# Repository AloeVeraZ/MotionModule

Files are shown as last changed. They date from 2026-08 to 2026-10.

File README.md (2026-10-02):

# MotionModule

> [!WARNING]
> **You are on `testing`, the experimental development branch.**
>
> Changes here are still being developed and tested. Running this branch may
> introduce bugs, break features that work on `main`, or change how your robot
> behaves. An update can also introduce new issues, even if an earlier testing
> version worked for you. Use [`main`](https://github.com/AloeVeraZ/MotionModule/tree/main)
> for normal robot use; choose `testing` when you want to try experimental changes
> and troubleshoot problems. Raise the wheels when checking a testing build.
>
> To return an installed controller to the main branch, run:
> ```bash
> motionmodule install main
> ```

MotionModule is an open-source Raspberry Pi robot controller for eight brushed
DC motors, a PCA9685 servo board with sixteen outputs, and a Pi-connected IMU.
The idea is to bring the controller and expansion functions of a REV Robotics
Control Hub and Expansion Hub together in one buildable, open-source project.
Anyone can build it using the supplied code, wiring guide, bill of materials
and enclosure CAD.

The reusable runtime owns GPIO, I2C, safety, networking, diagnostics, and the
browser dashboard. Each robot is one separate Python folder containing its own
behavior and an optional hardware map, so the same installation can run a Mecanum, tank,
walking, or other robot.

**Build it, wire it correctly, and run it from `main`.** The main branch is the
ready-to-use version for the documented hardware. Changes are developed and
tested on `testing` before they are merged into `main`; `testing` is the
development branch and can contain unfinished changes. The branches may match
immediately after a merge, then diverge as development continues.

Keep a physical motor-power cutoff within reach and raise the wheels when
checking a newly assembled robot. Follow the [wiring and power guide](docs/PINOUT.md).

## Wiring at a glance

The complete reference wiring below shows the Pi, all four motor drivers,
the PCA9685 servo board, the MPU6500 IMU and the power rails. Labels use
**physical Pi header pin numbers**. Wire colors match **Debug → Wiring →
Follow the signal** in the dashboard, which also includes this diagram below
**Names you can use in code**.

[Open the full-size diagram](docs/images/motionmodule-complete-wiring.png)
or use the [scalable SVG](docs/images/motionmodule-complete-wiring.svg).
See the [pinout guide](docs/PINOUT.md) for the connection tables and power details.

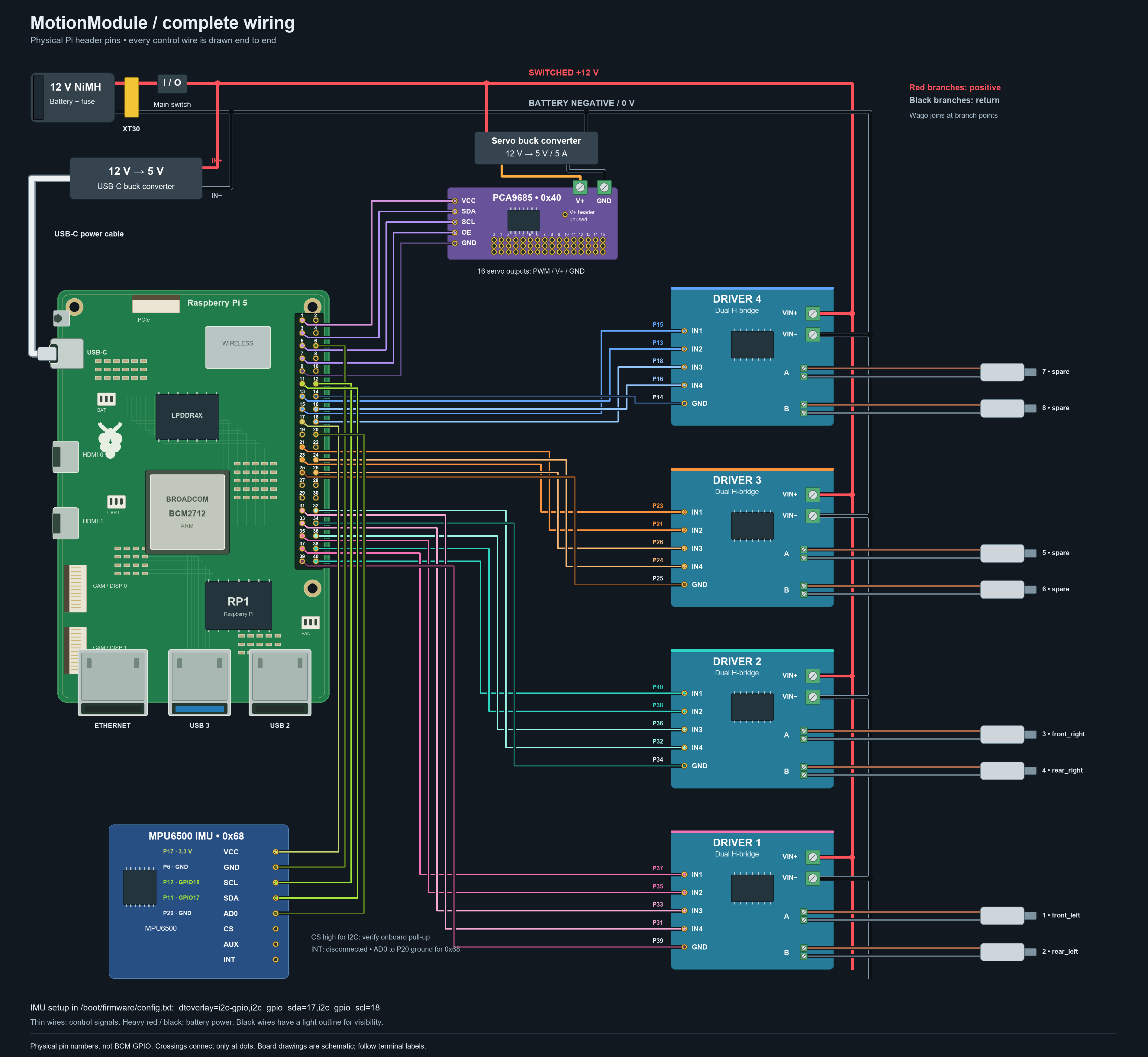
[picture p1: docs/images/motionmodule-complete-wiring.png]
Complete MotionModule wiring diagram


## Built for a personal Mecanum test robot

These photos show MotionModule in use on the owner's personal Mecanum testing
robot. The electronics are reusable; this four-wheel drivetrain is one example
of what the controller can run.

| Installed motion module | Controller with the cover removed |
| --- | --- |
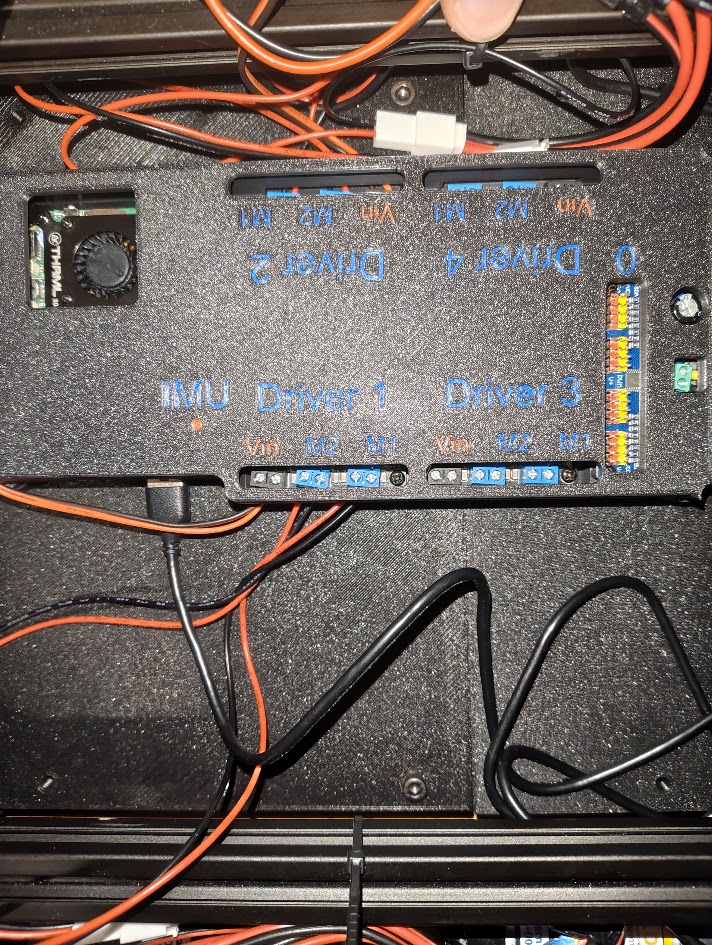
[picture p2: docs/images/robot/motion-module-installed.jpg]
MotionModule mounted in the Mecanum robot
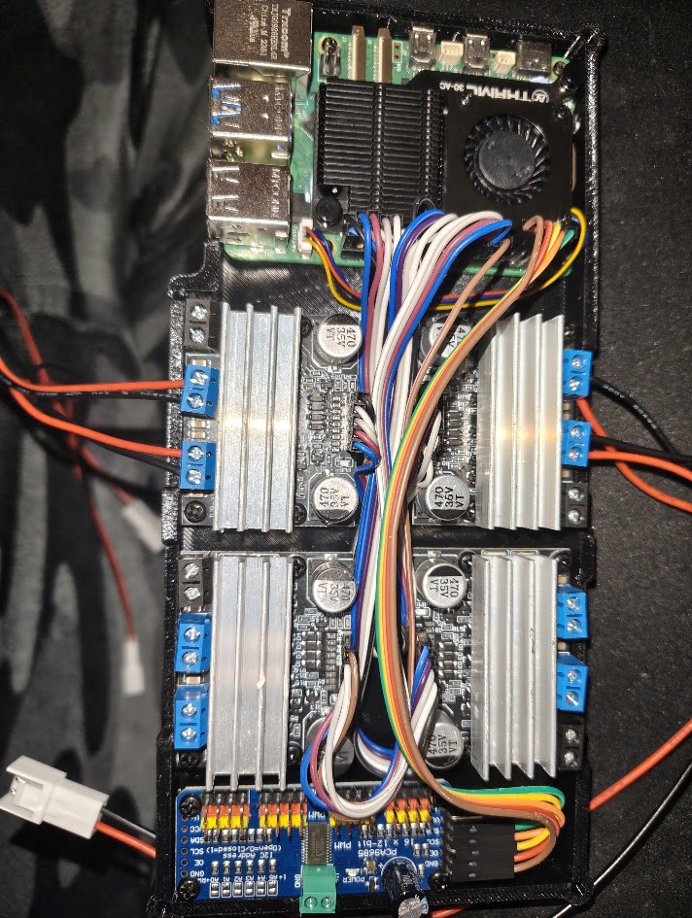
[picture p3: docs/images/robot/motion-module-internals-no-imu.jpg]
Pi, four motor drivers and PCA9685 inside the module, without the IMU plugged in
|  |  |

The open-module photo shows the build **without the IMU plugged in**. The
current build adds a Pi-connected MPU6500, supported by the included sensor
code for heading assist and autonomous turns. The labelled cover keeps the
motor-driver terminals and servo channels accessible.

<details>
<summary>Another view of the motion-module cover</summary>

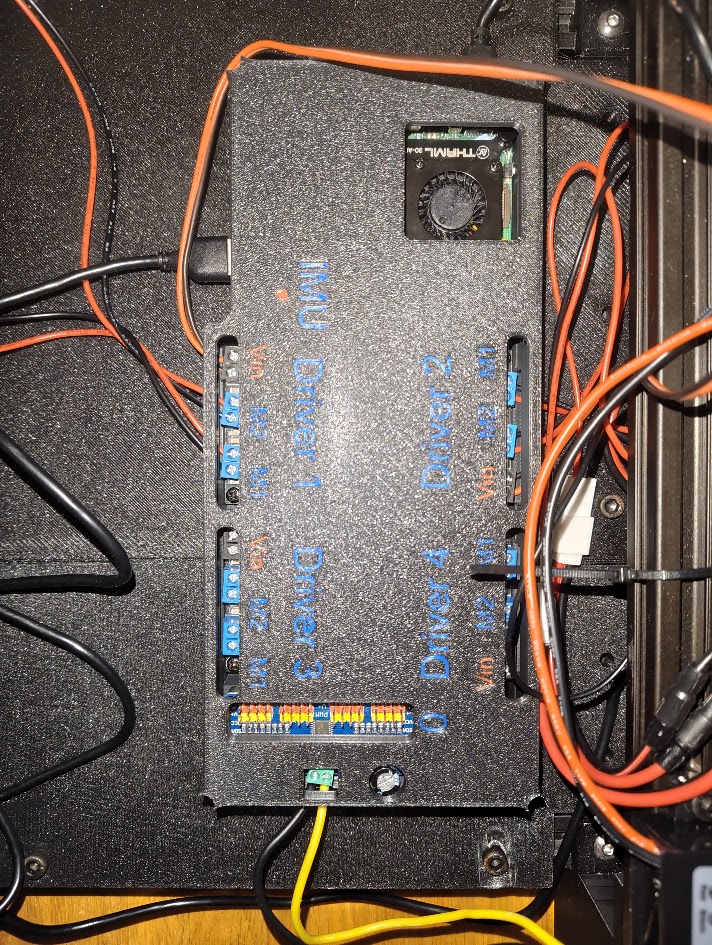
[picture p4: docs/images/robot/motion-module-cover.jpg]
Labelled motion-module cover and accessible connectors


</details>

### Battery and electronics box

| Battery module on the robot | Switch and battery lead |
| --- | --- |
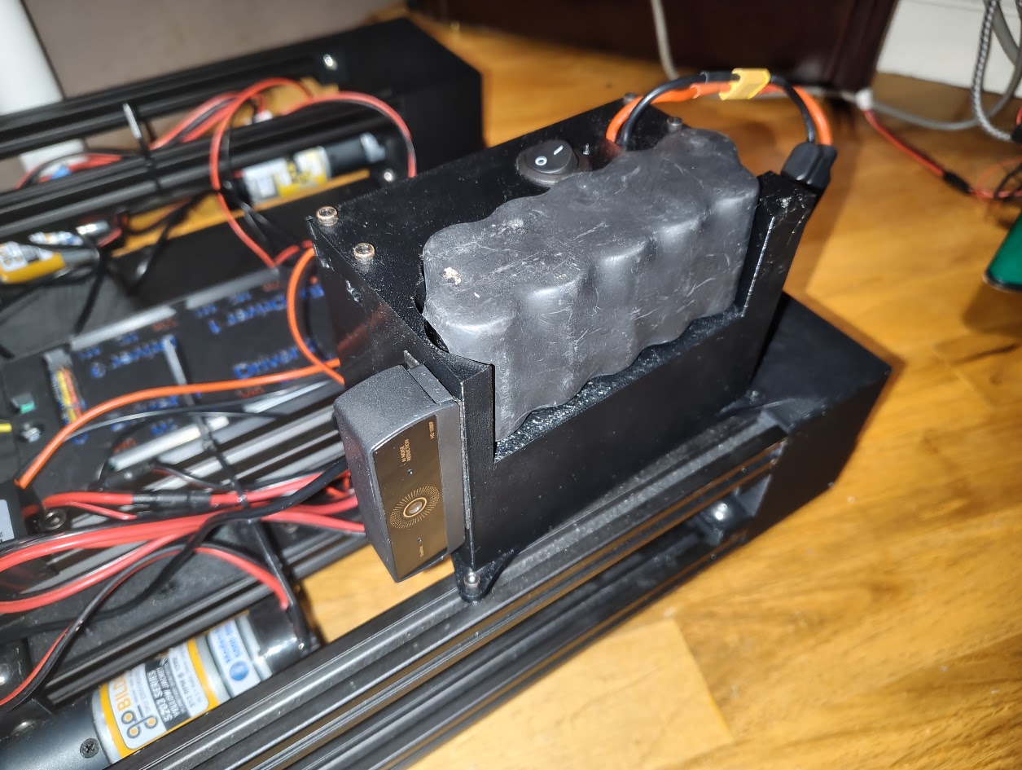
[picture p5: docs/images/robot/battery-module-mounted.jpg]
Battery module mounted on the Mecanum chassis
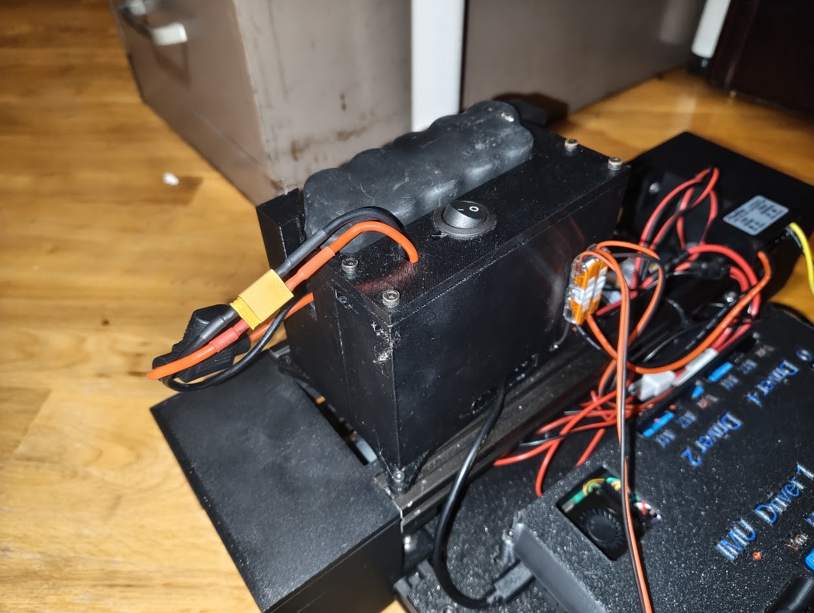
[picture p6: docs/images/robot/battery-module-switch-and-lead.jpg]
Electronics box with the rocker switch and outgoing battery lead
|  |  |

The electronics box accommodates both the **REV Slim and goBILDA 12 V NiMH
batteries** listed in the [bill of materials](BOM.md). One part holds the
battery, rocker switch and outgoing battery wire. The other part is an empty,
hollow enclosure for your 12 V wiring. In this robot, the buck converters and
power distribution feeding all four motor drivers are hidden inside that
compartment to keep the wiring cleaner.

### Full and Mini builds

| Build | Motor drivers | Motor outputs | Servo outputs | IMU |
| --- | ---: | ---: | ---: | --- |
| [MotionModule](MotionModule/README.md) | 4 | 8 | 16 | MPU6500 |
| [MotionModule Mini](MotionModuleMini/README.md) | 2 | 4 | 16 | MPU6500 |

Both builds share the same runtime, dashboard and robot API. Mini keeps channels
1–4 on the locked reference pins and omits Drivers 3 and 4. Its folder includes
the hardware profile, parts list and two-driver wiring diagram. On the Pi, run
`motionmodule install testing --variant mini` to try Mini, or select the module
in the dashboard Updates section. The installer preserves that choice across
updates. Change back with `--variant standard`; changing module keeps the same active robot project and every existing file. Mini is on testing pending review.

### Download the CAD

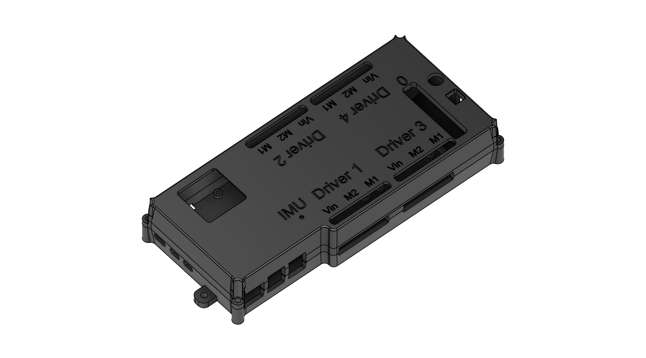
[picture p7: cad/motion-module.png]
Current motion-module enclosure CAD preview


| STEP model | What it contains |
| --- | --- |
| [Motion module](cad/motion-module.step) | Controller enclosure and mounting assembly |
| [Electronics box](cad/electronics-box.step) | Battery/switch section and hollow power-wiring compartment |

The dashboard also offers both files under **Debug → Parts list**, with direct
**Download STEP CAD** links that work on the robot hotspot without internet.
Import these STEP files into your CAD application. See the [CAD notes](cad/README.md)
for the assembly descriptions and the photos above for the installed examples.

## Try the dashboard without a robot

To show the dashboard off, or to work on it, run it on any computer. The demo
is the real dashboard and Driver Station connected to a simulated robot: arm
Drive and hold W and the motor bars move, the simulated cameras and IMU run,
the sensors change, and the example autonomous routine can be enabled. Nothing
touches hardware or the computer's network.

Windows, in PowerShell:

```powershell
irm https://raw.githubusercontent.com/AloeVeraZ/MotionModule/main/demo.ps1 | iex
```

macOS or Linux:

```bash
curl -fsSL https://raw.githubusercontent.com/AloeVeraZ/MotionModule/main/demo.sh | bash
```

The command downloads MotionModule, sets up its own Python environment (it
needs Python 3.11 or newer; on Windows it offers to install Python with winget
when there is none), and opens `http://127.0.0.1:8080` in the browser. Press
Ctrl+C to stop it. Running the command again fetches the latest version; with
no internet it reuses the last download.

In a clone of the repository, run `.\demo.ps1` or `./demo.sh` instead. That
copy is used as it is, so changes to the dashboard appear the next time the
demo starts.

To open the demo from a phone or tablet on the same Wi-Fi, set
`MOTIONMODULE_DEMO_HOST` to `0.0.0.0` before the command
(`$env:MOTIONMODULE_DEMO_HOST = '0.0.0.0'` in PowerShell, or
`export MOTIONMODULE_DEMO_HOST=0.0.0.0` in a Unix shell), allow Python through
the firewall if asked, and browse to the computer's IP address on port 8080.
`MOTIONMODULE_DEMO_BRANCH` picks another branch and `MOTIONMODULE_DEMO_PORT`
another port.

## Hardware

See the root-level **[bill of materials](BOM.md)** for the reference parts:

- Raspberry Pi 5 with a 40-pin header;
- four dual H-bridge boards for eight brushed-motor outputs;
- one PCA9685 I2C board, giving 16 servo channels;
- one 12 V battery for the whole robot, stepped down to 5 V USB-C for the Pi
  and to a separate regulated rail for the servos;
- Wago 221 lever connectors for the 12 V joins and ordinary jumper wires for
  the Pi's control signals; and
- a MPU6500 IMU on the Pi's independent I2C bus for heading; the robot can
  also drive without it. Optional USB GPIO expansion is separate from this setup.

Read the complete **[pinout and power boundaries](docs/PINOUT.md)** before
wiring. Never connect motor battery positive or the PCA9685 servo V+ rail to a
Pi header power pin.

The controller boards and the power module are what the robot actually needs;
motors, servos and wire below them are recommendations. Both batteries ship
already fused, so there is no separate breaker to buy. The enclosure STEP files are included in [cad/](cad/README.md). **Debug → Parts list** shows the whole reference
BOM, marked required or recommended, and works inside the app with no internet
connection.

## Install on a Raspberry Pi

In Raspberry Pi Imager, install current Raspberry Pi OS, create a normal
sudo-capable user, enable SSH for initial administration, and enter the Wi-Fi
the robot should prefer. Boot the Pi, connect once, and run:

```bash
curl -fsSL https://raw.githubusercontent.com/AloeVeraZ/MotionModule/main/install.sh | bash
```

Do not put `sudo` before that command. The installer:

1. installs all OS and Python dependencies;
2. creates a versioned runtime and persistent robot workspace;
3. configures the dashboard, GPIO/I2C access, mDNS, and Wi-Fi fallback;
4. runs the non-moving MotionModule Doctor automatically;
5. prints the GitHub pinout as its final message; and
6. reboots the Pi.

Fresh installs select Mecanum with teleop and the IMU autonomous routine ready
to use. Autonomous turns in place through 90°, 180°, 270°, and back to the
starting direction; it only moves after you Enable and press Start. Debug
Overview reports IMU activity as 1/1 or 0/1 responding. The Pi 5 fan uses
approximately 75% PWM at 47 °C and 100% at 50 °C after installation and reboot.

The first install uses hostname `motionmodule`. Give multiple robots unique
names with `--hostname motionmodule-01`. Updates are always explicit: the Pi
checks GitHub for a newer version and says so under **Debug -> Checks & logs**,
but nothing is ever installed until you press **Update now**.

## Connect to the robot UI

Put the computer on the same Wi-Fi as the Pi and open this in Chrome or Edge:

```text
http://motionmodule.local
```

The Pi's numeric IP also works. If no saved Wi-Fi connects within 30 seconds,
the robot creates its fallback hotspot:

```text
Network:  MotionModule
Password: motionrobot
Website:  http://10.42.0.1
```

The same Driver Station and deployment flow works through normal Wi-Fi,
Ethernet, or the robot hotspot. Debug shows the current hostname and every IP,
can scan and join another network, can start the hotspot for the current boot,
and can rename the robot. A reboot always tries saved Wi-Fi first.

## Dashboard

Three workspace pages plus the separate Driver Station:

- **Overview** — live motor power labelled with your own names, servo commands
  and I2C responses, watchdog state, temperature, memory, disk, uptime, network
  status, and a three-step guide for a first-time build.
- **Debug** — **Wiring** (colour-coded 40-pin header map, driver and servo
  wiring, separate 16-output servo-board diagrams, the names you can use in
  code, and USB inventory), **Parts** (complete reference BOM and enclosure CAD),
  **Tests** (guarded raised-wheel motor and servo tests, chosen by name),
  **Drive Test** (Mecanum by default; customize motor/servo mappings in `test.py`),
  **Checks & logs** (Doctor, service log, command reference), and **Network**
  (Wi-Fi, hostname, hotspot). Drive Test keeps fixed W/S, A/D, Q/E, and Space
  inputs. The sample ships with `test.py`; without one it uses the same built-in
  Mecanum mixer. See [custom Drive Test code](docs/CODING.md#optional-debug-drive-test-mapping).
- **Code** — **Deploy** a local Python folder and open the time-limited
  **Terminal**.
- **Open Driver Station** — launches the operator console, which runs the
  deployed project's own `drive()` and shows cameras, IMU, Pi inputs, USB
  sensor controllers, and the project's declared controls. A computer drives
  with the keys or a game controller; a phone or tablet drives with two
  on-screen sticks and shows only robot control, the sticks and the cameras,
  upright or on its side.

For the `Mecanum` project, **Use confirmed Mecanum mixer** starts checked in
the Driver Station. Manual movement then uses exactly the same mixer as
the default **Debug → Drive Test**, even if the Pi has older custom robot code. Uncheck
it to run the project's own `drive()` instead; changing it stops and disables
drive. Sensors, extra controls, and autonomous routines remain project-owned.
Other project names default to their own code. No saved project file is replaced.
Custom `test.py` mappings affect only Debug, not the full Driver Station.

Updates preserve NetworkManager's saved Wi-Fi profiles and MotionModule's
preferred-network setting. Updating while on the hotspot or disconnected does
not forget the saved Wi-Fi. The hotspot remains a fallback if reconnection fails;
an unavailable saved network cannot guarantee connectivity.

The dashboard and Driver Station share one look: condensed Barlow Condensed
headings over Inter text on a dark blueprint grid, with green, yellow, and red
status lights. A light theme is one click away in the top bar. The fonts ship
inside MotionModule, so the pages look the same on the robot hotspot with no
internet. The pages use no background animation or blur effects, so they stay
responsive when opened on a Raspberry Pi 3 with 1 GB of memory.

## Deploy robot code from the browser

No editor plugin or remote coding connection is required. Code the project in
any local editor, then:

1. Open **Code → Deploy** in the robot dashboard.
2. Press **Choose your robot folder**.
3. Select the whole folder containing `robot.py`.
4. Review the files, accept the stop/restart confirmation, and press
   **Deploy and run**.
5. Wait for the dashboard to reconnect after the service restarts.

The Pi accepts Python and project documentation only, checks every Python file,
parses any `hardware.py` without executing it, validates the pins and safety
limits, stops all outputs, backs up an older project with the same name,
atomically installs the new folder, makes it active, and restarts MotionModule.
A validation error leaves the working project in place.

Press **Download Mecanum sample** on that page for a complete starting folder.
Unzip it, rename the folder, edit it locally, and deploy the renamed folder.

## One hardware definition file

MotionModule ships with one editable `hardware.py` containing every motor's
name, BCM pin pair, inversion setting and driver/output explanation, plus
servo names, board addresses and timing settings. The installed copy is
`~/.config/motionmodule/hardware.py`. Debug and Code offer a download of the
configuration currently in use.

Your smallest browser project needs only `robot.py`: it uses the installed
hardware map. Add a `hardware.py` next to it when that robot needs different
names or wiring. MotionModule uses the project copy first, then the installed
map, then the default shipped with the runtime. Existing TOML configurations
remain supported for compatibility.

Use the names directly in your robot code:

```python
module.motor("driver_1a").set(0.25)
module.servo("servo_0").set_angle(90)
module.stop_all()
```

The Mecanum sample's own hardware file names its four wheels `front_left`,
`rear_left`, `front_right` and `rear_right`, preserving the tested pinout and
inversions. For your own robot, change a name in the hardware file and use
that name in code. No second pin-definition or driver-wrapper file is needed.

## Robot project format

Every project is self-contained, and only the first file is required:

```text
MyRobot/
├── robot.py          # required browser-control entry point
├── hardware.py       # optional: your own names, pins, and inversions
├── sensors.py        # the MPU6500 wired directly to the Pi
├── autonomous.py     # optional: the routine the robot runs by itself
├── dashboard.py      # optional: Driver Station cameras, sensors, keys, sticks
├── drivetrain.py     # optional Python modules
├── mechanisms.py
└── README.md         # optional project notes
```

### `hardware.py`

A project folder does not need this file. Include it only when this robot
needs its own names or wiring; without it, the robot uses the installed
hardware map described above.

`hardware.py` contains exactly one literal `HARDWARE` dictionary. It cannot
contain imports, function calls, calculations, or executable setup code. This
lets MotionModule validate an uploaded pinout without running student code.

```python
HARDWARE = {
    "module": {
        "pwm_hz": 1000,
        "deadtime_ms": 15,
        "watchdog_ms": 500,
    },
    "motors": {
        1: {
            "name": "left_drive",
            "forward_gpio": 26,   # physical pin 37
            "reverse_gpio": 19,   # physical pin 35, right next to it
            "inverted": False,
        },
        2: {
            "name": "right_drive",
            "forward_gpio": 13,   # physical pin 33
            "reverse_gpio": 6,    # physical pin 31
            "inverted": False,
        },
    },
    "servos": {
        "enabled": True,
        "i2c_bus": 1,
        "frequency_hz": 50,
        "addresses": [0x40],
        "minimum_pulse_us": 500,
        "maximum_pulse_us": 2500,
    },
}
```

Use BCM GPIO numbers in this file. Debug converts them to physical header pins
and lists every name it defines. The shipped `hardware.py` contains the complete
eight-motor reference map with a comment showing each output's driver, header
pin, and GPIO, so the easiest way to start is to download it from Debug or Code
and rename the outputs you actually use.

Every name must be unique across motors and servos, and must start with a
letter and use only letters, numbers, and underscores.

### `robot.py`

`robot.py` must define `create_drive(module)`. Return an object with
`drive(forward, strafe, rotate, speed)` and `stop()` methods. Do not move
hardware or start a permanent loop at import time, because the dashboard loads
this file during startup.

An optional sibling `dashboard.py` can define
`create_dashboard(module, drive)` to supply two camera feeds, one gyro/IMU,
Raspberry Pi digital inputs, and USB-controller analog/digital inputs to the
separate full Driver Station at `/driver-station`, and to lay out its keys,
game-controller sticks, touch sticks and phone panels. It is discovered
automatically and is not required for drivetrain debugging or robot control.
The complete contract and copyable example are in
[docs/CODING.md](docs/CODING.md#optional-full-driver-station-telemetry).

### Sensors: the Pi-connected MPU6500

The Mecanum robot's motors, PCA9685 servo controller and MPU6500 IMU connect
directly to the Raspberry Pi. `sensors.py` reads one MPU6500 on the independent
`i2c-gpio` bus: SDA on physical pin 11, SCL on 12, VCC on 17, GND on 6, and
AD0 on 20. Use the single [IMU wiring plan](docs/PINOUT.md#optional-mpu6500-six-axis-imu).
The Pi installer enables this bus for its next reboot. No extra sensors are declared.
The robot can still drive without an IMU; heading stays unavailable, the
driving assist switches off, and the sample autonomous routine does not move.
With the IMU, the default robot holds its heading while it drives. Its optional
autonomous routine performs four IMU-guided turns. The default Mecanum and
MecanumMini code is identical and declares no extra mechanism controls.

An **Arduino GIGA R1 WiFi** can optionally connect by USB for additional GPIO
inputs. The repository includes USB auto-detection, bridge firmware and a Python
pin API. This is an experimental extra, not part of the Mecanum setup; operation
on your board and sensors needs verification. Uno and Mega boards are not
supported by the bundled GIGA firmware. See [USB GPIO expansion](docs/CODING.md#optional-usb-gpio-expansion)
for the opt-in code and [setup](docs/SETUP.md#optional-usb-gpio-expansion) for flashing.

This is a complete two-sided drive example:

```python
LEFT = ("driver_1a", "driver_1b")
RIGHT = ("driver_2a", "driver_2b")

def clamp(value):
    return max(-1.0, min(1.0, value))

class TankDrive:
    def __init__(self, module):
        self.module = module

    def drive(self, forward, strafe, rotate, speed=0.5):
        # rotate +1 turns left (counter-clockwise): left side back, right forward
        left = forward - rotate
        right = forward + rotate
        scale = max(1.0, abs(left), abs(right))
        outputs = {name: clamp(left / scale * speed) for name in LEFT}
        outputs.update({name: clamp(right / scale * speed) for name in RIGHT})
        self.module.set_motors(outputs)
        return {"outputs": outputs}

    def stop(self):
        self.module.set_motors({name: 0 for name in LEFT + RIGHT})

def create_drive(module):
    return TankDrive(module)
```

Those four names come from the shipped `hardware.py`. Rename them there to
`left_front`, `right_rear`, or whatever matches your machine, and use the new
names here.

The Driver Station supplies values from `-1.0` to `1.0` for `forward`,
`strafe`, and `rotate`; `speed` is its `0.0` to `1.0` limit. The returned
dictionary must contain JSON-compatible data.

### Motors

Use a name from the active `hardware.py`, or a motor channel from 1–8:

```python
intake = module.motor("driver_3a")  # or module.motor(5)
intake.set(0.30)
intake.stop()
```

Update a drivetrain together, by name or by channel:

```python
module.set_motors({"driver_1a": 0.4, "driver_1b": 0.4, "driver_2a": 0.4, "driver_2b": 0.4})
```

Values are clamped to `-1.0` through `1.0`. MotionModule applies the project
inversion map, inserts coast time before a direction reversal, and refreshes
the watchdog. Keep nonzero commands arriving faster than the configured
watchdog timeout and call `module.stop_all()` for a whole-robot stop.

### Servos

Use a servo name, or an explicit board/channel pair. PCA9685 boards count
from 0, and each has channels 0–15:

```python
claw = module.servo("servo_0")  # or module.servo(channel=0, board=0)
claw.set_angle(30)
claw.set_angle(110)
claw.release()
```

For a calibrated positional or continuous-rotation servo, use a verified pulse
inside the configured range:

```python
claw.set_pulse_us(1500)
```

The Debug servo tool includes generic 180°/360° position profiles and goBILDA
position, five-turn, and continuous-rotation profiles. `release()` disables
the PWM signal; it does not first move a mechanism to a safe pose.

## What MotionModule can detect

- A PCA9685 can acknowledge its I2C address, so Debug reports detected or no
  response for each configured board.
- USB devices identify themselves. Debug lists their product, vendor/product
  ID, Pi port, Linux driver, device file, and whether the service user has
  access. This is live inventory, not firmware management.
- The reference H-bridge inputs and ordinary servos have no return data. The Pi
  cannot prove that a board, motor, or servo is plugged into those output-only
  wires. Debug labels those outputs as configured but unverified; use the
  guarded bench tests with the robot raised.

## How the system works together

```text
Chrome / Edge on robot network
          │ HTTP
          ▼
       Nginx :80
          │ local proxy
          ▼
MotionModule dashboard + active Python project
          ├── GPIO PWM → four H-bridges → eight motor outputs
          ├── I2C → PCA9685 board(s) → servo channels
          ├── sysfs → read-only USB inventory
          └── watchdog → stops stale motor commands
```

The service loads `~/MotionModule/active/robot.py`. `active` points to one
folder under `~/MotionModule/robots`; browser uploads preserve previous copies
under `~/MotionModule/backups`. Runtime releases live separately, so installing
or rolling back MotionModule keeps every existing robot project, including
unedited samples. Each install snapshots robot code under `~/MotionModule/backups`
before it changes the runtime. Changing module or branch keeps the active project.
Both modules share channels 1–4, all servo outputs and the IMU; Mini omits channels
5–8 in memory without rewriting hardware.py. Switching to full MotionModule
restores omitted ports 5–8 on the locked reference wiring, including when keeping
the MecanumMini project. Debug and motor tests follow that installed capacity.
Code using unavailable outputs or an
incompatible API may need changes, but its files remain available in recovery mode.
Before a branch or version handoff, the current CLI also saves a snapshot so
code remains recoverable if you deliberately install an older release whose
installer predates this policy. Such an older installer may refresh bundled
samples; your original copy remains in `~/MotionModule/backups`.
The one legacy exception is the recognized retired pin map: it is migrated to the
locked wiring, keeping the old hardware file and the pre-update snapshot.

The network service tries saved Wi-Fi for 30 seconds and creates the fallback
hotspot only when none connects. Nginx provides the same port-80 page in either
mode.

## Keep a copy and share diagnostics

**Code → Deploy → Download active robot** saves the active project's code,
original hardware.py and calibration data as a ZIP. It works in recovery mode
and does not activate a different project or change outputs. Runtime pipes,
symlinks, caches and dependency folders are excluded; the limit is 32 MiB and
2,000 files. Keep the ZIP on your computer and extract it before editing or
uploading the project folder again.

**Debug → Checks & logs → Download diagnostic report** saves a timestamped JSON
report with the installed module, branch and commit, motor/servo wiring, system
status and check results. It omits robot source, recovery tracebacks, service
logs and Wi-Fi credentials. Both downloads require the dashboard's current session.

The dashboard and Driver Station allow only one pending status or telemetry
poll at a time. Stalled requests time out and recover on later polls; slower
Wi-Fi scans have their own longer timeout. Command delivery and the motor
watchdog keep their existing timing.

## Debugging and terminal

Use this order:

1. Open **Debug** and inspect warnings, the active pinout, USB/I2C devices,
   network addresses, and service log.
2. Run `motionmodule doctor`; it does not intentionally move hardware.
3. Run `motionmodule pinout` and compare every wire before applying power.
4. Raise the robot and use the guarded Motor Bench Test at half power.
5. Select the correct board, channel, and behavior in Servo Pulse Test.
6. Check `motionmodule logs` after a failed project start.

The web terminal at the bottom of Code is a real, unprivileged Bash shell. For
security it needs a short-lived code created during an admin SSH session:

```bash
motionmodule terminal enable       # valid for 15 minutes
motionmodule terminal enable 30    # choose 1–120 minutes
motionmodule terminal disable
```

Enter the printed code in the webpage. The grant expires automatically, is
invalid after reboot, and an idle shell closes after five minutes. The robot UI
uses HTTP, so never put reusable passwords or tokens in this terminal and never
expose it to the public internet.

Useful commands are also explained inside Debug:

| Command | Purpose |
| --- | --- |
| `motionmodule status` | Show the service state |
| `motionmodule doctor` | Run non-moving checks |
| `motionmodule pinout` | Print the physical wiring map |
| `motionmodule restart` | Stop outputs and reload the active project |
| `motionmodule logs` | Follow Python and service output |
| `motionmodule project list` | List installed robot folders |
| `motionmodule project NAME` | Select another installed folder |
| `motionmodule versions` | List installed runtime versions |
| `motionmodule rollback` | Return to the earlier release of the same branch |
| `motionmodule install main` | Replace MotionModule with a branch, tag, or commit |
| `motionmodule giga flash` | Install the sensor firmware on the plugged-in Arduino GIGA |
| `motionmodule giga status` | Show the GIGA, the bundled firmware, and `dfu-util` |

## Updates and development

Open **Debug -> Checks & logs** in the dashboard. A Pi with internet access
asks GitHub what each branch is on and shows a line per branch: green when
this robot is running the newest version, red with **Update now** when one is
waiting. A Pi on `testing` also sees the `main` line, so it can go back; a Pi
on `main` sees only `main`. Pressing the button stops the motors, runs the
update as root in the background, and automatically reboots the whole Pi after
a successful install; the log appears under the card while it works. The
dashboard waits for the Pi to come back. If `sudo` on the Pi asks for a
password, a popup asks for it first, and the update uses it only while it runs.
Nothing installs on its own.

The same thing over SSH:

```bash
motionmodule install main
motionmodule versions
motionmodule rollback
```

Installing replaces the MotionModule software rather than stacking versions,
so the `main` and `testing` branches are interchangeable: a Pi on either one
can install the other, in either direction. Robot projects and their backups,
the active project, `hardware.py` pin names, and Wi-Fi settings are always
kept. `motionmodule rollback` returns to the earlier release of the same
branch when one is kept; to change branches, install the other one. The
[installer notes](installer/README.md) list exactly what is removed.

To test the repository without robot hardware:

```bash
python -m venv .venv
python -m pip install -e .
python -m unittest discover -s tests -v
python -m motion_module doctor
```

Set `MOTIONMODULE_MOCK=1` on a Pi to avoid claiming GPIO and I2C hardware.
Detailed references are in [Setup](docs/SETUP.md), [Coding](docs/CODING.md),
[Pinout](docs/PINOUT.md), and [Architecture](docs/ARCHITECTURE.md).

## Repository layout

```text
MotionModule/
├── core/motion_module/    # controller, safety, dashboard, deploy, USB, network
│   ├── hardware.py        # the shipped pin and name definitions
│   └── hardware_guide.py  # offline parts list and wiring reference
├── installer/             # Pi install, services, Wi-Fi, versions, rollback
├── cad/                   # motion-module and electronics-box STEP models
├── docs/                  # guides, wiring diagram, and reference-build photos
├── examples/
│   └── Mecanum/           # complete downloadable Python robot folder
│       ├── robot.py
│       └── hardware.py
├── tests/                 # hardware-independent automated tests
├── BOM.md
├── install.sh
├── requirements.txt
└── pyproject.toml
```

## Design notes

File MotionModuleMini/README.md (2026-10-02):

# MotionModule Mini

Mini has **4 motor outputs on 2 dual H-bridge boards**, **16 servo outputs on
one PCA9685**, and the same Pi-connected **MPU6500 IMU** as the full module.
It runs the same shared runtime, robot API, watchdog, dashboard and Driver Station.
Only the hardware profile and build references differ.

- [Mini bill of materials](BOM.md)
- [Mini pinout](PINOUT.md)
- [Hardware definition](hardware.py)
- [Four-wheel Mecanum sample](../examples/MecanumMini)
- [Full MotionModule](../MotionModule/README.md)

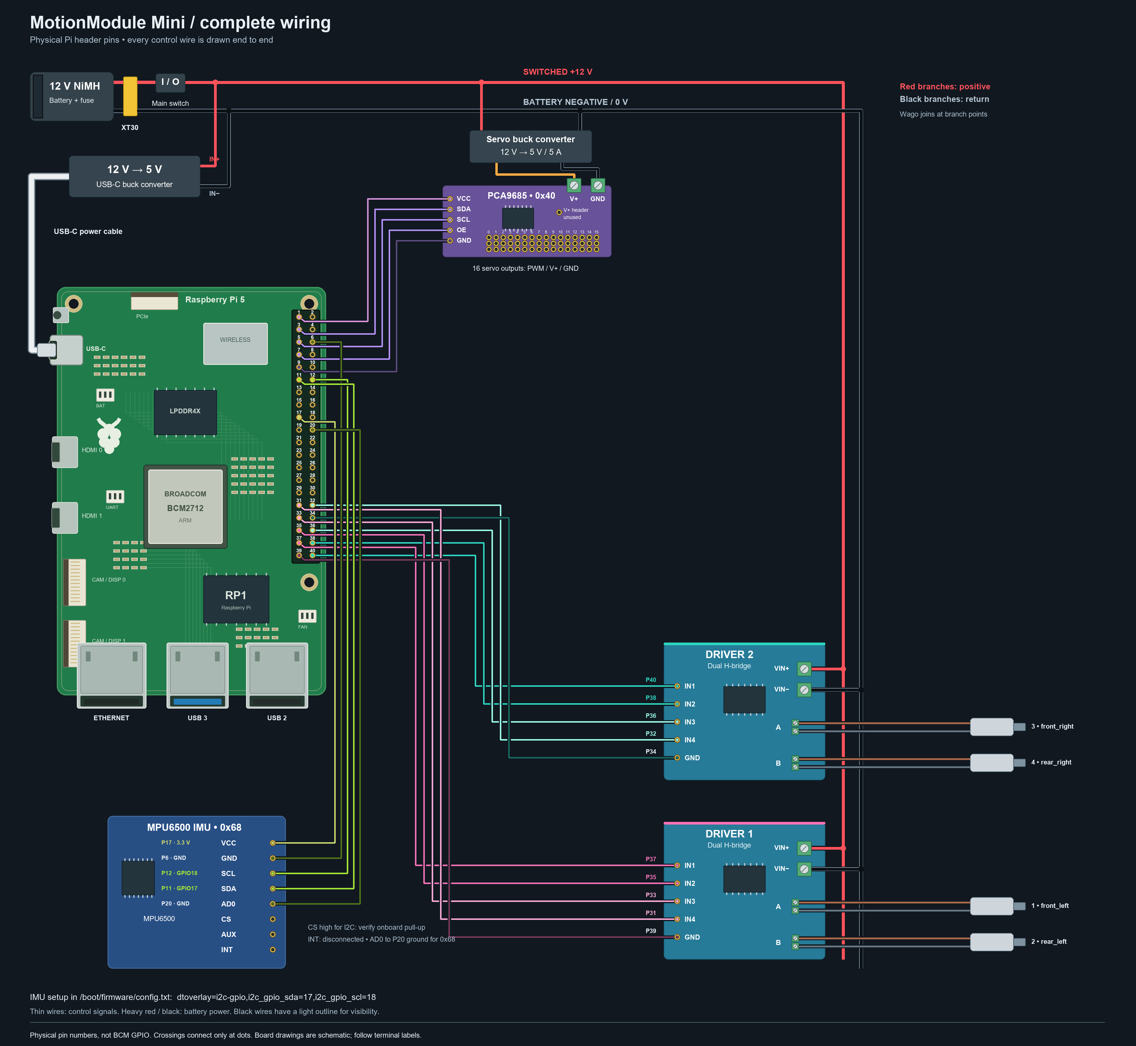
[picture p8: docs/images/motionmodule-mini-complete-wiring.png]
Complete Mini wiring: two drivers, four motors, PCA9685 and IMU


## Install and try

On an installed Pi:

```bash
motionmodule install testing --variant mini
```

From a repository checkout on a fresh Pi:

```bash
bash install.sh --version testing --variant mini
```

The installer starts the MecanumMini sample for a Mini install. The sample's
robot, autonomous, sensor and dashboard code is identical to the full Mecanum
sample; its hardware definition includes only wheel channels 1–4. Existing
robot folders are kept. For custom code, copy the Mini hardware definition into
your robot folder, retain channels 1–4 and rename outputs for your mechanisms.
Motor direction is changed with `inverted`, never by moving pins.

The installed Mini limit persists across updates and project changes. The existing hardware file is preserved; channels 5–8 are omitted from the
runtime map on Mini. Code requesting those motors gets an unavailable-output error. Debug and the
motor activity display show four outputs; servo and IMU behavior stays the same.
Switching back to full MotionModule restores ports 5–8 on their locked pins in
memory, even when the active project is MecanumMini. Debug, the 40-pin header,
and individual motor tests then show all eight ports on four drivers. The four
wheel names, inversion settings, servo configuration and robot files are kept.

To run the simulated Mini dashboard on Windows:

```powershell
$env:MOTIONMODULE_VARIANT = "mini"
python -m motion_module.demo --no-browser
```

On Linux/macOS:

```bash
MOTIONMODULE_VARIANT=mini python -m motion_module.demo --no-browser
```

## Switching builds

Updates shows both the installed module and its main/testing branch. Choose
MotionModule or MotionModule Mini, then install the desired branch. A module
change keeps the same active robot project and files, saves a pre-update code
snapshot in `~/MotionModule/backups`, and reboots using the selected hardware limit. The current Mini implementation
is on testing; main gains it only after review and merge.

The full module's enclosure STEP model and 22-M3-screw count describe the full
assembly. Mini-specific enclosure CAD and its final mounting screw total have
not been supplied. The Mini wiring diagram is a schematic, not enclosure CAD.

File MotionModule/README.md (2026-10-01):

# MotionModule

The full module has **8 motor outputs on 4 dual H-bridge boards**, **16 servo
outputs on one PCA9685**, and a Pi-connected MPU6500 IMU.

Both builds use the same [runtime](../core/motion_module), dashboard, robot API,
watchdog and Driver Station. This folder holds the full build's default
[hardware definition](hardware.py); the shipped default and existing installer
paths stay in place.

- [Full bill of materials](../BOM.md)
- [Full wiring guide](../docs/PINOUT.md)
- [Complete wiring diagram](../docs/images/motionmodule-complete-wiring.png)
- [Enclosure CAD and assembly](../cad/README.md)
- [MotionModule Mini](../MotionModuleMini/README.md)

Install the full module from testing on the Pi:

```bash
motionmodule install testing --variant standard
```

For a fresh install from a repository checkout:

```bash
bash install.sh --version testing --variant standard
```

The dashboard Updates page shows the installed module and branch. Its module
selector can install either build; changing module keeps your active robot project and its files.

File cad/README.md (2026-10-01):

# Reference-build CAD

These STEP models come from the owner's personal Mecanum testing robot.

Current motion-module enclosure CAD preview

| File | Assembly |
| --- | --- |
| [motion-module.step](motion-module.step) | Motion-module controller enclosure and mounting assembly for the Pi, four dual motor drivers and PCA9685 servo board |
| [electronics-box.step](electronics-box.step) | Electronics/battery box with a battery-and-switch section and a hollow power-wiring compartment |

The electronics box works with the REV Slim and goBILDA 12 V NiMH batteries
listed in the [bill of materials](../BOM.md). The battery section includes the
rocker switch and outgoing battery lead. The hollow section holds your 12 V
wiring; the reference robot hides its buck converters and motor-driver power
distribution inside it for cleaner wiring.

Import the `.step` files into a CAD application to inspect the assemblies and
prepare individual parts for manufacture. These are the supplied STEP models;
no STL files or print settings are included.

For the motion-module assembly, use **four M2.3 × 5 mm self-tapping screws**
to mount the Raspberry Pi. Use **22 M3 × 5 mm self-tapping screws in total**
for all four motor-driver boards, the PCA9685 servo board, the IMU and the
enclosure. This total includes **four corner screws**, one at each corner,
to fasten the top plate to the bottom plate; the remaining screws mount the
boards, one per mounting hole. See the [mounting screw table](../BOM.md#motion-module-mounting-screws).

See the [installed photos and wiring diagram](../README.md#wiring-at-a-glance).
The open-controller photo predates plugging in the IMU; the current build and
sample code use a Pi-connected MPU6500. Enclosure labels identify connectors;
the [pinout guide](../docs/PINOUT.md) defines the locked electrical wiring.

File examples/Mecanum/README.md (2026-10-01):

# Mecanum sample robot

Six small Python files make the complete sample. Only one is required.

| File | What it does | Required? |
| --- | --- | --- |
| `robot.py` | Turns drive commands into wheel power | Yes |
| `test.py` | Debug Drive Test motor/servo mapping | No — without it, the same built-in Mecanum test runs |
| `hardware.py` | Names each motor and servo, and holds the pins | No — delete it to use the built-in names |
| `sensors.py` | MPU6500 read directly by the Pi | Included; missing hardware is shown offline |
| `autonomous.py` | The routine the robot runs by itself | No — delete it and there is no autonomous mode |
| `dashboard.py` | Driver Station cameras, sensors, keys, and sticks | No — delete it without affecting driving |

## Try it

1. Open the robot dashboard, go to **Code**, and press **Download Mecanum sample**.
2. Unzip it and rename the folder to your robot's name.
3. Edit `robot.py` in any editor.
4. Back in **Code**, choose that folder and press **Deploy and run**.

## The wheels

`hardware.py` gives channels 1-4 these names, and `robot.py` uses them:

| Name | Channel | Driver board | Board inputs | Motor terminal |
| --- | ---: | --- | --- | --- |
| `front_left` | 1 | Driver 1 · A | IN1, IN2 | MOTOR_A |
| `rear_left` | 2 | Driver 1 · B | IN3, IN4 | MOTOR_B |
| `front_right` | 3 | Driver 2 · A | IN1, IN2 | MOTOR_A |
| `rear_right` | 4 | Driver 2 · B | IN3, IN4 | MOTOR_B |

This is the reference wiring the sample expects. On the controller plate, with
the Pi on the left and its USB ports at the bottom, Driver 1 sits beside the
USB ports, Driver 2 above it, Driver 3 to the right of Driver 1 and Driver 4
above Driver 3. **Debug -> Wiring guide** shows every wire. Wire the same way
to run the sample unchanged, or change the pins in `hardware.py` to match your
own wiring.

The drivetrain uses normal polarity for motors 1 and 3 and inverted polarity
for motor 2 / Driver 1B (`rear_left`) and motor 4 / Driver 2B (`rear_right`).
Both Test outputs and Drive use this same `hardware.py`; inversion is applied
once, when the runtime writes to the GPIOs. Never add another inversion in
`mix()`.

Older Mecanum projects without a `hardware.py` use the Pi's installed hardware
file instead. An update now gives that project its own copy of those existing
settings with inversion enabled for motors 2 and 4, retaining its motor names,
other motors' polarity, all other settings, and its existing code. The installed
file remains untouched.
An existing project `hardware.py` is preserved unless the entire folder is
recognized as an unmodified shipped sample.

## Add a mechanism

Channels 5-8 and all sixteen servo outputs are free. Rename them in
`hardware.py`, then use those names:

```python
intake = module.motor("intake")
intake.set(0.35)
intake.stop()

claw = module.servo("claw")
claw.set_angle(90)
claw.release()
```

## Driving

After deploying, open **Driver Station**, tick the enable box, then use W/S to
drive, A/D to strafe, Q/E to rotate, and Space to stop. Start with the speed
limit low.

On a phone or tablet the keys give way to two on-screen sticks: the left one
drives and strafes all the way round, the right one turns left and right. Lift
your thumbs to stop; the red button disables everything. Turned on its side, a
phone keeps the sticks in the bottom corners, and the page shows only robot
control, the sticks and the cameras.

The sample imports `motion_module.mecanum.mix`, the same confirmed mixer used
by the default **Debug → Drive Test**. Forward, strafe, rotation, and combined commands
therefore have one implementation. `hardware.py` still supplies the names,
locked pins, and per-motor polarity; no extra inversion is applied in `robot.py`.

For an existing project named `Mecanum`, the full Driver Station also defaults
to **Use confirmed Mecanum mixer**. This lets older preserved `robot.py` files
use the proven movement without being overwritten. Unchecking it uses that
file's own drive method. Sensors and extra controls still come from the project;
autonomous code is not overridden. Changing the selection stops and disables drive.

## Customize Drive Test

`test.py` is loaded automatically beside `robot.py`, only for **Debug → Drive Test**.
It returns the existing confirmed Mecanum test by default. To test tank, swerve,
or other output mappings, replace its `create_test(module)` implementation with
an object exposing `drive(forward, strafe, rotate, speed)` and `stop()`.
Use the supplied module for motor and servo commands. W/S, A/D, Q/E, and Space
stay fixed; only the outputs associated with the inputs change. Space always
stops all motors and releases servos. Do not move hardware during import or
construction, and do not start background loops. Redeploy the folder to reload.
See [the hook contract](../../docs/CODING.md#optional-debug-drive-test-mapping).
The full Driver Station's `robot.py` behavior is independent of this file.

## Autonomous

`autonomous.py` is optional and is found automatically beside `robot.py`. With
it there, the Driver Station's mode switch offers **AUTONOMOUS** next to
**TELEOPERATED**; pick it, tick the safety box, and **RUN AUTO** starts the
routine. The sample drives forward, turns, then strafes, and stops itself.

Every step is a loop that keeps sending drive commands, because the motor
watchdog stops the robot as soon as commands stop arriving. Each loop checks
`stop.is_set()` so DISABLE ends the routine promptly — and MotionModule stops
the outputs immediately either way. `duration_seconds` cuts off a routine that
never returns. While it runs, manual driving is refused, so the driver and the
routine cannot fight over the motors.

## Sensors: the Pi-connected MPU6500

`sensors.py` reads one MPU6500 directly from the Pi, shared by `robot.py`,
`autonomous.py` and `dashboard.py`. Follow [the reference IMU wiring](../../docs/PINOUT.md#optional-mpu6500-six-axis-imu):
VCC to physical pin 17, GND to 6 and AD0 to 20, SDA to 11 and SCL to 12.
The Pi installer enables the `i2c-gpio` overlay for its next reboot. The module
discovers the bus and MPU6500 address, then closes its reader on shutdown.
Motors and servos keep their Pi wiring.

Heading increases turning left, like `rotate`. Missing hardware is shown as
offline. The Pi uses gyro and accelerometer readings; the DMP is not used.
Mount +Y forward and +Z upward.

The default sample declares no mechanism controls: driving uses the normal
keyboard, gamepad or touch inputs. Mecanum and MecanumMini use identical robot,
test, sensor and dashboard code; only their hardware maps differ in capacity.
Heading hold starts enabled and keeps the direction while driving or strafing.
The IMU panel still provides gyroscope calibration. Custom robot code can use
`Sensors.zero_heading()` or the heading helper directly when needed.

Tuning lives in `HEADING` at the top of `robot.py`; see
[heading control](../../docs/CODING.md#heading-control-motion_moduleheading).

`autonomous.py` turns in place to 90°, 180°, 270°, then 360° (back to the
starting direction). Each turn uses the confirmed teleop Mecanum mixer and
PD heading correction, settling within 2° before continuing. A turn that
cannot settle within 6 seconds fails and stops the routine. It never drives
forward or strafes. Angles count from the heading when Start is pressed.

Choose Autonomous, confirm the area is clear, Enable, then Start Autonomous.
The driver-input panel becomes the command list with live target, heading,
and error. After completion, Enable and Start again to repeat. Edit `PLAN`
to change the routine. Deploy this folder first; updating MotionModule keeps
owner-edited robot folders, so an old folder may have no autonomous.py.

Calibrate gyroscope beside the IMU display (also in Debug → Test outputs)
stops outputs, measures gyro bias, and sets the current heading, pitch and
roll to zero. Keep the robot stationary. Rate should read near zero at rest;
it is a measurement and will still show sensor noise. This calibration does
not tune the heading controller. Adjust `HEADING` in robot.py from observed
turns: lower kp or raise kd for overshoot; raise minimum turn power if stalled.
The default PD gains are simulation-tested, not physically tuned for your floor.

No extra sensors are declared. An Arduino **GIGA R1 WiFi** can provide optional
USB GPIO inputs for future additions using the existing auto-detection and
bridge API. This experimental feature may need troubleshooting; it is not
required for the Mecanum robot. See [the opt-in API](../../docs/CODING.md#optional-usb-gpio-expansion).

## Full Driver Station: cameras, IMU, and sensors

`dashboard.py` is discovered automatically when it is beside `robot.py`.
**Debug → Drive Test** uses `test.py`, not this telemetry hook or `robot.py`.
Press **Open Driver Station** for the independent operator
console, which does. The sample declares a front camera and shows the Pi
MPU6500 on the heading dial. Its additional USB sensor list is empty.
USB cameras are discovered automatically; an external stream URL is optional.

`driver_bindings()` in the same file decides which keys the Driver Station
listens for. The sample keeps the usual W/S, A/D, Q/E and space; return only
what you want to move. `gamepad_sticks()` and `touch_sticks()` decide which
stick of a game controller, and of the on-screen pair, drives, strafes and
turns, and `touch_panels()` adds panels to a phone's layout. The sample spells
out every default; see [the Driver Station's controls](../../docs/CODING.md#the-driver-stations-controls).
This is the robot's own layout and is unrelated to the **Debug → Drive Test**,
whose keys are fixed.

The camera selector shows the front feed, rear feed, or both square viewports.

Before putting the robot on the floor, use **Debug → Motor bench test** with
every wheel off the ground and confirm each named motor turns the way you
expect.

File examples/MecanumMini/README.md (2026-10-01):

# Mecanum Mini sample

The same four-wheel robot, autonomous, sensor and dashboard code as
[Mecanum](../Mecanum), using a Mini hardware definition: two dual H-bridge
boards and four motor channels. All sixteen PCA9685 servo channels and the
Pi-connected MPU6500 remain available.

Use the [Mini setup](../../MotionModuleMini/README.md),
[Mini parts list](../../MotionModuleMini/BOM.md) and
[Mini pinout](../../MotionModuleMini/PINOUT.md). No spare motor channels are
configured; channels 1–4 keep their locked pins and wheel names.

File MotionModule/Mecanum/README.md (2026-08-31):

# Mecanum example

This is the student-editable robot project. The versioned MotionModule runtime
hosts the browser dashboard, while `robot.py` supplies its drive hook and
`mecanum.py` contains the wheel math. Future installs update the dashboard
without overwriting this folder.

`Mecanum` is not required by the core. Add `Swerve`, `WalkingRobot`, or another
folder beside it with its own `robot.py`, then run
`motionmodule project PROJECT_NAME` on the Pi to activate it.

The first four motor channels are:

| Wheel | Channel |
| --- | ---: |
| Front left | 1 |
| Rear left | 2 |
| Front right | 3 |
| Rear right | 4 |

The mixer uses the standard left-versus-right rotation pattern. If a physical
wheel runs backward, edit only that motor's `inverted` setting in
`~/.config/motionmodule/config.toml`, then run `motionmodule restart`. Do not
change the rotation signs to compensate for one reversed motor.

Open `http://motionmodule.local` (or the Pi's IP address) after installation.
Use W/S to move, A/D to strafe, Q/E to rotate, and Space to stop. The dashboard
refreshes the 500 ms hardware watchdog every 80 ms while driving. Its Network
page shows every Pi IP and provides Wi-Fi scan, preferred-network, and robot
hotspot controls. Starting a network change stops all motors first.

After editing either file, run `motionmodule restart`. Older student folders
that contain the original Flask server remain compatible: MotionModule loads
their drive class and ignores the old page server.

To use a servo from your own code:

```python
arm = module.servo(channel=0, board=0)
arm.set_angle(90)
arm.release()
```

To use an extra motor:

```python
intake = module.motor(5)
intake.set(0.35)
intake.stop()
```

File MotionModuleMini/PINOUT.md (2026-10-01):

# MotionModule Mini pinout

Mini retains the locked channels 1–4 from the full module. It uses **two dual
motor drivers for four motors**. Drivers 3 and 4 are omitted; no remaining
connection is moved. Physical pin numbers refer to the Pi 40-pin header;
GPIO numbers are BCM.

Complete Mini wiring

| Channel | Default name | Mecanum wheel | Driver / output | Forward wire | Reverse wire | Driver ground |
| ---: | --- | --- | --- | --- | --- | --- |
| 1 | driver_1a | front_left | Driver 1 / A | pin 37 / GPIO26 → IN1 | pin 35 / GPIO19 → IN2 | pin 39 |
| 2 | driver_1b | rear_left | Driver 1 / B | pin 33 / GPIO13 → IN3 | pin 31 / GPIO6 → IN4 | pin 39 |
| 3 | driver_2a | front_right | Driver 2 / A | pin 40 / GPIO21 → IN1 | pin 38 / GPIO20 → IN2 | pin 34 |
| 4 | driver_2b | rear_right | Driver 2 / B | pin 36 / GPIO16 → IN3 | pin 32 / GPIO12 → IN4 | pin 34 |

Motor outputs A and B connect to their respective motors. Supply each driver
from switched 12 V and return its power ground directly to battery ground;
Pi ground wires carry the signal reference, not motor current.

## PCA9685: all sixteen servo outputs

| Pi connection | PCA9685 connection |
| --- | --- |
| pin 1 / 3.3 V | VCC, logic only |
| pin 3 / GPIO2 | SDA |
| pin 5 / GPIO3 | SCL |
| pin 7 / GPIO4 | OE, active low |
| pin 9 / GND | Logic GND |

Use address 0x40 with all address pads open. Servo V+ comes from its own
regulated supply; join its return at common ground. Never connect V+ or motor
battery positive to a Pi header pin. All sixteen PWM / V+ / GND output headers
remain available.

## MPU6500: same independent I²C bus

| Pi connection | IMU connection |
| --- | --- |
| pin 17 / 3.3 V | VCC / VIN |
| pin 6 / GND | GND |
| pin 11 / GPIO17 | SDA |
| pin 12 / GPIO18 | SCL |
| pin 20 / GND | AD0, selects 0x68 |

Keep CS high for I²C (verify the board's pull-up); leave INT and auxiliary pins
disconnected. The installer enables `i2c-gpio` with SDA 17 and SCL 18.
Reboot after installation. Use the same [IMU setup and robot API](../docs/CODING.md#pi-connected-mpu6500-imu).

## Unused pins

The former Driver 3 and 4 signal pins (13, 15, 16, 18, 21, 23, 24, 26) and
signal ground pins 14 and 25 stay disconnected on Mini. Pins 8/10 are reserved
for UART and 27/28 for ID EEPROM. Pins 2/4 are unused 5 V power pins; pins 19,
22 and 29 are unused GPIOs and pin 30 is an unused ground. Changing a motor's
`inverted` value changes its direction without changing this wiring.

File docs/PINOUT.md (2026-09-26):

# MotionModule pinout and power wiring

Software uses **BCM GPIO numbers**. Connector diagrams use **physical header
numbers**. Every table below shows both; never assume they are interchangeable.
Use this wiring guide together with the root-level [bill of materials](../BOM.md).
Both are built into **Debug → Wiring** and **Debug → Parts** in the robot
dashboard, so the guide works on the robot hotspot without internet access.
The dashboard uses the active configuration's names and pins; the tables here
describe the reference harness.

> [!IMPORTANT]
> **This wiring is locked.** The reference robot is wired exactly as these
> tables show, and that wiring works. The built-in `hardware.py`, the Mecanum
> sample, the dashboard's wiring guide and `motionmodule pinout` all use it, on
> `main` and on `testing`, and no change may move a pin, driver or ground.
> [AGENTS.md](../AGENTS.md) explains, and `tests/test_wiring_lock.py` fails if
> any of it changes. A robot wired another way keeps its own `hardware.py`.

## Read the connector before connecting a wire

The Pi has **40 physical header pins**, with two numbering systems:

- **Physical pin** is the numbered position on the connector, from 1 to 40.
- **GPIO / BCM** is the signal number used in `hardware.py`. For example,
  GPIO12 is **physical pin 32**, not physical pin 12.

In Debug, select a header pin to see its destination and purpose. A motor
signal label means a wire to an H-bridge input, not a connection directly to
the motor. The motor's two heavy wires go to that driver's output pair.
Confirm pin 1 using the Pi/header markings; a diagram can be rotated relative
to the board on your bench.

The dashboard draws the Pi 5 the way it sits on the reference controller
plate: USB and Ethernet ports at the bottom, the 40-pin header down the right
edge. Held that way, pin 1 is the top pin of the row nearer the middle of the
board and pin 2 sits beside it on the board edge. Odd pins run down the inner
row and even pins down the outer row, exactly as the pin list beside the
drawing reads.

## Four dual H-bridge boards

Each GODIYMODULES board controls two motors. Its control header reads
`IN1 IN2 IN3 IN4 GND`: **IN1 and IN2 drive the board's MOTOR_A terminal
(output A), and IN3 and IN4 drive MOTOR_B (output B).** So `1A` is Driver 1's
MOTOR_A, wired from IN1 and IN2, and `1B` is Driver 1's MOTOR_B, wired from IN3
and IN4; drivers 2, 3 and 4 follow the same pattern. The inputs accept 3-18 V,
so the Pi's 3.3 V signals drive them directly. VIN+ and VIN- take the 12 V
battery, and GND joins the Pi's ground as the signal reference. Connect each
motor only to its own terminal pair.

Two inputs drive one motor:

| First input (IN1 or IN3) | Second input (IN2 or IN4) | Motor |
| --- | --- | --- |
| Speed signal (PWM) | Off | Forward |
| Off | Speed signal (PWM) | Reverse |
| Off | Off | Stopped (coasts) |

Which way counts as forward depends on how the motor's two wires sit in the
terminal. Set `inverted` in `hardware.py` rather than swapping wires.

| Driver | Output | Motor channel | Default code name | Forward wire | Reverse wire | Pi ground |
| ---: | :---: | ---: | --- | --- | --- | --- |
| 1 | A | 1 | `driver_1a` | IN1 · physical 37 / GPIO26 | IN2 · physical 35 / GPIO19 | physical 39 |
| 1 | B | 2 | `driver_1b` | IN3 · physical 33 / GPIO13 | IN4 · physical 31 / GPIO6 | physical 39 |
| 2 | A | 3 | `driver_2a` | IN1 · physical 40 / GPIO21 | IN2 · physical 38 / GPIO20 | physical 34 |
| 2 | B | 4 | `driver_2b` | IN3 · physical 36 / GPIO16 | IN4 · physical 32 / GPIO12 | physical 34 |
| 3 | A | 5 | `driver_3a` | IN1 · physical 23 / GPIO11 | IN2 · physical 21 / GPIO9 | physical 25 |
| 3 | B | 6 | `driver_3b` | IN3 · physical 26 / GPIO7 | IN4 · physical 24 / GPIO8 | physical 25 |
| 4 | A | 7 | `driver_4a` | IN1 · physical 15 / GPIO22 | IN2 · physical 13 / GPIO27 | physical 14 |
| 4 | B | 8 | `driver_4b` | IN3 · physical 18 / GPIO24 | IN4 · physical 16 / GPIO23 | physical 14 |

**Where each driver sits.** On the reference controller plate, with the Pi on
the left and its USB ports at the bottom, Driver 1 sits beside the USB ports,
Driver 2 above it, Driver 3 to the right of Driver 1 and Driver 4 above
Driver 3. That is the wiring the project's Mecanum sample expects, with its
wheels on Drivers 1 and 2. Wire the same way to run the sample unchanged, or
change the pins in `hardware.py` to match your own wiring.

The default name is the driver position, so no lookup is needed to find the
wire. Rename any of them in `hardware.py` and the dashboard follows: the
Mecanum sample renames channels 1-4 to `front_left`, `rear_left`,
`front_right` and `rear_right`.

**Each driver is one short bundle of wires.** Its four signal pins and its
ground sit in a single run of header positions, so you wire a driver without
tracing across the board:

| Driver | Signal pins | Ground | Shape |
| ---: | --- | ---: | --- |
| 1 | 31, 33, 35, 37 | 39 | Five in a row down the left column |
| 2 | 32, 36, 38, 40 | 34 | Five in a row down the right column |
| 3 | 21, 23 and 24, 26 | 25 | Facing pairs, ground between them |
| 4 | 13, 15 and 16, 18 | 14 | Facing pairs, ground between them |

Drivers 1 and 2 face each other across the bottom of the connector. Every
motor's two inputs are neighbouring positions on the same side, except
Driver 2's output B, whose inputs sit either side of that driver's own ground
at physical 34.

Seven GPIOs stay free for later use: physical 8, 10, 11, 12, 19, 22 and 29.
That includes the whole default UART pair (physical 8 and 10), so the GPIO
serial console still works. Physical 7 (GPIO4) carries the servo board's OE
wire.

This direct-GPIO profile intentionally supports four dual drivers/eight motors.
Adding still more direct H-bridges would consume pins reserved for other Pi
interfaces and increase boot-state/PWM complexity. Expand servos freely by I2C;
for more than eight brushed motors, add an addressed motor-control/PWM expansion
board and a new software backend instead of casually taking the ID or UART pins.

GPIO7/8/9/11 normally have alternate SPI functions. The reference Raspberry Pi
OS image has SPI disabled. `motionmodule doctor` warns if a `/dev/spidev*`
device is active; disable SPI before using Driver 3.

Raspberry Pi GPIOs are inputs during early boot, so they cannot be relied on to
hold a driver input low until Linux and the MotionModule service have started.
Keep motor power physically switched off through boot and watch that every
output stays still before you trust it. If a particular driver does twitch at
boot, a 10 kΩ pull-down from that input to signal ground holds it low.

## PCA9685 servo controller

The servo board is a separate I2C device and shares no motor GPIO. Its 16
servo outputs live **on the PCA9685 board**, not on 16 Pi pins. Five Pi wires
run to it, and they sit in one unbroken run down the top of the left column —
pins 1, 3, 5, 7, 9 — so the whole board is a single bundle. Pins 8 and 10 are
left free for the serial console.

| PCA9685 connection | Raspberry Pi / supply connection | What it is for |
| --- | --- | --- |
| VCC (logic) | physical pin 1 / 3.3 V | Powers the chip only, about 10 mA |
| SDA | physical pin 3 / GPIO2 | Commands, and the answer that proves the board is present |
| SCL | physical pin 5 / GPIO3 | Clocks that data |
| OE | physical pin 7 / GPIO4 | Enables and disables all 16 outputs |
| GND | physical pin 9 / ground | Reference for SDA, SCL and OE |
| V+ screw terminal | separate regulated servo supply positive | The only supply that moves servos |
| V+ screw terminal GND | servo supply negative and common logic ground | Returns servo current to its own supply |
| **V+ header pin** | **nothing** | Same copper as the screw terminal — see below |

### OE, the output enable pin

OE is active low. MotionModule holds it low so the outputs are enabled, and
drives it high to cut all sixteen at once. Because OE is a wire and not an I2C
register, that cut still works if the bus has stopped answering.

The board pulls OE low by itself, so the outputs are enabled any time the Pi is
not driving that pin — including through boot, before Linux claims GPIO4. That
is safe, because the PCA9685 powers up with every channel off, but it does mean
**OE is an enable line, not a power cutoff.** Keep the physical cutoff.

The reference `servos.output_enable_gpio` stays fixed at GPIO4. A separately
wired robot uses its own `hardware.py`. From robot code:

```python
module.set_servo_outputs_enabled(False)   # cut all 16 outputs at the board
module.set_servo_outputs_enabled(True)    # allow them again
module.servo_outputs_enabled              # what the pin is doing right now
```

### Do not wire the V+ header pin to the Pi

The V+ header pin and the two-screw power terminal are the same net on this
board — Adafruit's own guide says you can "inject power from the 2-pin terminal
block", meaning the pin already carries whatever the terminal is fed. It exists
to pass that rail to a second board.

So if the servo rail is on the terminal and you also run the V+ header pin to a
Pi 5 V pin, you have connected the servo supply directly to the Pi's 5 V rail.
With a 12 V rail on that terminal, 12 V lands on the Pi. Leave it disconnected.

Adafruit rates the board itself for up to 12 V on V+ ("you should provide
5-6VDC if you are using servos … if you have to, you can go higher to 12VDC"),
but that voltage reaches the middle contact of all sixteen outputs, so every
servo plugged in sees it. Hobby servos want 5–6 V and an Axon Mini MK2 tops out
at 8.4 V. Feed V+ the stepped-down rail, not the battery.

### The 16 servo output headers

Each numbered output has **three contacts**. Follow the board's printed
signal/V+/GND labels and the servo's connector specification, rather than
assuming wire colors or board orientation:

| Contact on each output | Connect to | What it does |
| --- | --- | --- |
| Signal / PWM | That servo's signal wire | Carries the command for this one channel |
| V+ | That servo's power wire | Shared regulated servo supply, not Pi logic power |
| GND | That servo's ground wire | Returns power to the servo supply |

The first board has these default code names. They match the channel numbers
printed on the board, so `servo_5` is the output labelled 5. Rename them in
`hardware.py` to match your mechanisms. A configured name does not prove a
servo is plugged in.

| Board output | Default code name | Board output | Default code name |
| ---: | --- | ---: | --- |
| 0 | `servo_0` | 8 | `servo_8` |
| 1 | `servo_1` | 9 | `servo_9` |
| 2 | `servo_2` | 10 | `servo_10` |
| 3 | `servo_3` | 11 | `servo_11` |
| 4 | `servo_4` | 12 | `servo_12` |
| 5 | `servo_5` | 13 | `servo_13` |
| 6 | `servo_6` | 14 | `servo_14` |
| 7 | `servo_7` | 15 | `servo_15` |

### Other connectors and pads

- **OE (output enable):** low enables the PWM outputs, high disables them.
  It is wired to physical pin 7 / GPIO4, as described under
  [OE, the output enable pin](#oe-the-output-enable-pin).
  Disabling PWM does not disconnect the servo power rail.
- **A0–A5:** solder address pads, not servo outputs. They choose which I2C
  address this board responds to.
- **Repeated side headers:** repeated SDA/SCL/VCC/GND labels are the same
  electrical connections for chaining another controller. They do not each
  need a separate Pi pin. V+ remains the separate servo power rail.

The [PCA9685 datasheet](https://www.nxp.com/docs/en/data-sheet/PCA9685.pdf)
documents OE and address inputs. The
[PCA9685 connector reference](https://learn.adafruit.com/16-channel-pwm-servo-driver/pinouts)
explains the common breakout layout; match labels on the selected AITRIP board
before wiring, since board orientation and fitted components can differ.

> [!WARNING]
> `VCC` powers PCA9685 logic. `V+` powers the servos. Do not bridge them and do
> not power a bank of servos from a Raspberry Pi 5 V header pin.

The first board has every address pad open and uses `0x40`. To add another
board, solder A0 on the second board for `0x41`, chain SDA/SCL/VCC/GND, provide
appropriately sized servo power, and edit:

```python
# In HARDWARE["servos"] in hardware.py:
"addresses": [0x40, 0x41],
```

Code then uses `module.servo(channel=0, board=1)` for the second board. Never
put two boards with the same address on one bus. The hardware can address many
boards, but wire length, bus capacitance, connector current, and power
distribution become the practical limits well before the advertised maximum.

If `servos.channels` contains an explicit list of named outputs, also add names
with `"board": 1` and channels 0–15 for the second board. If you omit that
optional dictionary, MotionModule automatically names every output on every
configured board. Debug always shows all 16 physical headers per board, even
when only some have explicit names.

## Reserved and unused Pi header pins

"Reserved" means kept for a specific electrical interface. It does not mean
that a sensor is connected. The base harness leaves the following spare pins
available; the optional IMU extension below uses pins 6, 11, 12 and 17.

| Physical pin(s) | Reference purpose | What to do |
| --- | --- | --- |
| 1, 3, 5, 7, 9 | PCA9685 logic: VCC, SDA, SCL, OE, GND | Connect the five logic wires above; GPIO2/3 stay reserved for I2C even if servo support is disabled |
| 8 / GPIO14, 10 / GPIO15 | UART transmit and receive | Leave disconnected in the default harness; serial access may use them |
| 27 / GPIO0, 28 / GPIO1 | HAT ID EEPROM data and clock | Leave disconnected; MotionModule rejects motor use of these pins |
| 2, 4 | Pi 5 V power | Not used by the reference harness; never connect the motor battery or servo V+ here |
| 17 | Spare Pi 3.3 V logic power | Unused; not a motor or servo supply |
| 6, 20, 30 | Spare Pi ground | Available for low-current signal references |
| 11, 12, 19, 22, 29 | Unassigned GPIO17/18/10/25/5 | No configured device or sensor; alternate interfaces may use these pins |

If you customize motor pins, Debug shows the **active assignment** in place of
the reference label. For example, using a UART GPIO for a motor requires
disabling its serial-console/UART use first. Do not treat an unused label as a
guarantee that another Pi service is not using that pin.

## Optional MPU6500 six-axis IMU

The [selected JESSINIE board](https://www.amazon.com/dp/B0GTVCCY6B) was sold
as MPU9255, but the installed board reports MPU6500 identity `0x70`.
MotionModule supports this MPU6500 over the independent Pi I2C bus.
Match printed signal labels, not header positions. Every motor and PCA9685
wire stays in place.

| Board signal | Connection / purpose |
| --- | --- |
| VCC | Pi pin 17, 3.3 V |
| GND | Pi pin 6, ground |
| SCL | Pi pin 12, GPIO18, software I2C clock |
| SDA | Pi pin 11, GPIO17, software I2C data |
| AD0 / SDO | Pi pin 20 ground (secondary IMU ground), selects address 0x68 |
| CS / NCS | Must be high for I2C; verify the breakout's onboard pull-up |
| INT | Leave disconnected; the driver polls the sensor |
| EDA / ECL / FSYNC and other auxiliary pins | Leave disconnected; not used by MotionModule |

SDA/SCL need pull-ups to 3.3 V. Verify the board's I2C mode and pull-ups;
never use 5 V. No additional Pi GPIO is used.

The driver checks WHO_AM_I register 0x75 for MPU6500 identity 0x70,
initializes the gyro and
accelerometer, and calibrates while still. It supplies relative heading,
pitch, roll and turn rate; it does not use the DMP. Mount
+Y forward and +Z upward. Relative heading can drift; zero before a run.
### First setup and a missing sensor

No firmware flashing is needed for this driver. If the supplied header is
loose, solder it to the board; pushing pins through bare holes is not a
reliable electrical connection. Match the printed labels in the table above.
Check that NCS is held high for I2C and that SDA/SCL have pull-ups to 3.3 V;
the product photo does not establish which resistors the delivered board has.

The sample uses `IMUConfig("Main IMU", address=0x68)` from
`motion_module.imu`. Old `GigaIMU(...)` declarations in customized robot
folders still load from 0.12.1 and read the same MPU6500; replace them with
that configuration when you next edit them. Restart the robot
service after installing the update. The driver accepts only MPU6500 identity
`0x70`; other identities are rejected before configuration writes.

Run **Debug → Checks & logs**. Expect MPU6500 identity `0x70` at `0x68`
(`0x69` means AD0 is high). A responding address alone does not identify the
chip. If neither address responds, check power, solder joints, signal labels,
NCS and pull-ups before blaming calibration. Keep the robot still during
startup calibration, then zero heading before driving. The runtime initializes
the gyro and accelerometer automatically.

With power off, wire the board. The Pi installer adds this under `[all]` in
`/boot/firmware/config.txt` (older Pi OS: `/boot/config.txt`) and reboots.
For a setup without the installer, add it manually and reboot:

```ini
dtoverlay=i2c-gpio,i2c_gpio_sda=17,i2c_gpio_scl=18
```

Debug → Wiring shows the optional connections even before hardware is present.
Checks & logs verifies the MPU6500 chip ID on the independent bus, below the
PCA9685 checks. Detection is not proof of calibration or usable heading.
[LocalIMU setup](CODING.md) explains how robot code initializes and reads it.

## Power boundaries

Use three planned power domains:

1. Raspberry Pi logic power from a stable Pi-rated 5 V regulator.
2. Motor power from the robot battery through a main switch and correctly sized
   fuses to each driver branch.
3. Servo power from a separate regulated rail set for the connected servos,
   normally 5–6 V for standard hobby servos.

Join their negatives at a deliberate common reference point so 3.3 V control
signals have a return path. Do **not** route motor current through a Pi ground
pin: the heavy driver power negatives return directly to the battery/power
distribution bus, while the Pi ground wires are only low-current signal
references.

The Amazon listing's 10 A figure does not override a motor's stall-current
requirement. Measure or obtain each motor's stall current, fuse below the safe
wire/connector/driver limit, and add the recommended heat sinking/airflow for
high continuous current. Use one motor per H-bridge channel.

## First electrical test

1. Disconnect battery and servo power.
2. Verify every BCM/physical pin against the tables with a continuity meter.
3. Verify no motor supply positive is connected to a Pi header pin.
4. Set the servo regulator voltage before attaching servos.
5. Put the chassis on a stable stand with all wheels clear.
6. Power the Pi first with motor power still off, and run
   `motionmodule doctor`.
7. Apply motor power with the physical cutoff in reach.
8. Stop the service and pulse one channel: `motionmodule stop`, then
   `motionmodule test-motor 1`.
9. Test each channel and label the resulting physical wheel/mechanism.
10. Restart normal code only after the map is verified: `motionmodule start`.

## A Pi set up before the rewiring

Until 6 September 2026 every pin map MotionModule shipped put the motors on
other pins, `front_left` on GPIO12 and GPIO6, `rear_left` on GPIO19 and GPIO16
and so on, and left the servo board's OE unwired. An install keeps the robot
folders and `~/.config/motionmodule/hardware.py` it finds, so a Pi set up before
then kept that pin map, and its dashboard kept drawing it, after the robot was
rewired to the tables above.

Every install now checks for it. A `hardware.py` whose motors all sit on those
old pins is replaced with the one this release ships: the Mecanum sample's in
`robots/Mecanum`, the built-in one in `~/.config/motionmodule/hardware.py`. The
old file stays beside it as `hardware.py.retired-wiring`, and the install log
says what moved. The new file brings the shipped `inverted` values, so repeat
the first electrical test above and fix `inverted` on any wheel that turns the
wrong way before driving. A `hardware.py` with any other pins is the robot's own and is
never changed.

## Complete wiring diagram

Complete MotionModule wiring diagram

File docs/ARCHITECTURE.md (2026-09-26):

# Runtime and update architecture

## Control path

```text
browser → nginx :80 → versioned dashboard :8080
                           │
                           ├── browser project deployment
active robot folder ───────┤
                           ├── GPIO PWM → four dual H-bridges → eight motors
                           ├── independent Pi I2C → MPU6500 IMU
                           ├── I2C → PCA9685 board(s) → servos
                           ├── USB serial → optional GIGA GPIO inputs (experimental)
                           ├── dfu-util → GIGA bootloader (firmware installs)
                           └── time-limited PTY Bash terminal
```

All motor writes share a lock. A logical sign reversal coasts all motors for
the configured deadtime, and a watchdog stops all output after the configured
period without a control heartbeat. GPIO starts low and is forced low on normal
shutdown and handled Python exceptions. Software safety does not replace a
fused power system and physical cutoff.

## Runtime and project separation

```text
~/.local/share/motionmodule/
├── current -> releases/main-...
├── previous -> releases/main-...        # only an earlier release of the same branch
└── releases/

~/MotionModule/
├── active -> robots/Mecanum/
├── robots/
│   ├── Mecanum/
│   │   ├── robot.py
│   │   ├── hardware.py
│   │   ├── sensors.py
│   │   ├── autonomous.py
│   │   └── dashboard.py
│   └── AnotherRobot/
└── backups/

~/.config/motionmodule/hardware.py       # installed pin and name definitions
~/.config/motionmodule/config.toml       # pre-hardware.py installs only
~/.config/motionmodule/terminal-access.json
```

Installing a tag, branch, or commit builds and tests a new release before the
`current` link changes. It does not overwrite the work in a robot project: a
folder still holding an untouched copy of a sample takes the sample the new
release ships, with the replaced folder kept under `backups/`, and a folder
with one file of its own is left as it is. Once the new release is running,
the install replaces the old MotionModule software: other
releases and stale MotionModule system files are removed, so `main` and
`testing` can replace each other in either direction. Only an earlier release
of the same branch is kept, for rollback. Rollback switches the runtime links,
not the student folders. See [installer/README.md](../installer/README.md) for
exactly what is removed and what is kept.

The service follows `~/MotionModule/active/robot.py` and auto-loads an optional
sibling `dashboard.py` for the separate full Driver Station's camera, IMU, Pi
input, and USB-controller telemetry. GPIO and servo
configuration is resolved in one order: the active project's data-only
`hardware.py`, then the installed `~/.config/motionmodule/hardware.py`, then the
copy shipped inside the runtime. Installs predating that file keep their TOML
configuration, which is still read for compatibility.

## Browser deployment boundary

The Code page sends a browser-selected directory as multipart files to the
local dashboard. The backend:

1. requires the unguessable per-page dashboard token;
2. accepts a single safe root folder with Python, Arduino sketches, and text documentation only;
3. enforces count, individual-file, and total-size limits;
4. rejects path traversal, links, binary data, caches, and build output;
5. compiles every `.py`, verifies `create_drive(module)`, verifies
   `create_dashboard(module, drive)` when `dashboard.py` exists, and, when the
   folder ships one, parses `hardware.py` with `ast.literal_eval` without
   importing it;
6. stops outputs before writing project state;
7. moves an existing target to `backups`, atomically installs the staged
   folder, and atomically updates `active`; and
8. exits so systemd restarts the dashboard on the new project.

The service uses `Restart=always`, so a deliberate clean exit after deployment
returns through the same launcher. Nginx stays the stable port-80 front door.

## Connectivity

```text
boot
  │
  ├── saved Wi-Fi connects within 30 seconds → hostname.local + DHCP IP
  │
  └── no saved connection → MotionModule hotspot → http://10.42.0.1
```

Ethernet also reaches the same dashboard. A root-owned NetworkManager helper
exposes only fixed status, scan, connect, preferred-network, hotspot, and
hostname operations to the unprivileged service. A manual hotspot is for the
current boot; the next boot tries saved client Wi-Fi again.

## Hardware discovery limits

PCA9685 boards acknowledge on I2C. USB devices expose descriptors in Linux
sysfs, so the dashboard can list identity, topology, driver binding, device
node, and permission status. The Arduino GIGA R1 WiFi is matched by its
official USB VID/PID: 2341:0266 running a sketch, 2341:0366 in its bootloader.
USB discovery alone cannot identify which physical sensor is wired to a pin.

## Reference Pi IMU

The Mecanum sample declares one MPU6500 at its default address 0x68.
`module.local_imu()` finds the independent `i2c-gpio` adapter, detects the
chip at 0x68 or 0x69, creates a `LocalIMU` and closes it on
module shutdown. Simulation and a missing overlay return no reader; the
sample reports heading unavailable. The wiring is the single plan in
Debug → Wiring and PINOUT.md. Motors and the PCA9685 also connect to the Pi.
No additional sensors are declared by the sample.

## Optional Arduino GIGA USB GPIO expansion

```text
firmware/giga_sensor_bridge/giga_sensor_bridge.ino   the firmware, generic
firmware/giga_sensor_bridge.bin                      prebuilt, flashed by the Pi
firmware/giga_sensor_bridge.json                     version and checksums
firmware/build.py                                    rebuilds the binary (arduino-cli)
```

The firmware only moves bytes: it reads the pins and I2C registers it is told
to, at the interval it is told, and answers one-off reads, writes and bus
scans. An opt-in project extension declares additional GPIO inputs;
`module.giga()` creates one `GigaR1Bridge` for the process (never opened in simulation), and
its reader thread sends `MM3 CONFIG <id> <ms> <pins> <streams>` after every
connection. The GIGA answers with one JSON line of readings per interval,
tagged with that id, so readings meant for another configuration are never
used. The original `MM1 CONFIG` pins-only protocol is still understood in both
directions, so older MotionModule software and the original sketch keep
working; firmware whose protocol this version cannot use is reported as
needing a flash rather than guessed at.

This experimental extension targets GIGA R1 WiFi, not Uno or Mega. Hardware
operation needs verification; it is not required by the reference robot.
The Python bridge configures GPIO inputs only. Generic I2C commands remain
in the Arduino firmware for custom extensions, but no bundled sensor-specific
IMU drivers run over USB. The built-in MPU6500 is read only by `LocalIMU` on
the Pi's independent I2C bus. Its driver measures gyro bias while still,
tracks tilt with the accelerometer, and integrates relative yaw about the
measured up direction. Positive yaw is counter-clockwise, matching `rotate`.

`motionmodule giga flash` and Debug's Install firmware button run
`motion_module.giga_firmware`: the reader releases the port, a 1200-baud touch
restarts the board into its bootloader, `dfu-util` writes the bundled binary at
0x08040000, and the board's version is checked once it restarts. The installer
provides `dfu-util`, the `dialout` and `plugdev` groups, and a udev rule for the
GIGA's USB IDs. `tests/firmware/harness.cpp` runs the real firmware against
simulated I2C chips, and `tests/fake_giga.py` tests GPIO input transport against a
simulated board, so both sides are tested without hardware.

The reference GPIO H-bridges and PWM servo signal have no return channel.
MotionModule can validate their configured pins and safely pulse an output, but
it cannot electronically prove a driver, motor, or servo is attached.

## Web terminal

The terminal API requires the per-page dashboard token and a second temporary
access code created by `motionmodule terminal enable`. The code is stored with
mode 0600, expires, and is tied to the current Linux boot ID. The backend owns
one unprivileged PTY at a time, caps retained output and input, and closes idle
sessions.

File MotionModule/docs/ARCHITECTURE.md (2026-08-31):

# Runtime and update architecture

## Control path

```text
browser ---> nginx :80 ---> versioned dashboard :8080
                              |
active robot/robot.py ------- drive hook
        |
        v
motion_module.MotionModule
   |                     |
   v                     v
lgpio 1 kHz PWM          I2C bus 1
16 direction legs        PCA9685 0x40, 0x41, ...
   |                     |
4 dual H-bridges         16 servos per board
   |
8 brushed motors
```

All motor writes go through one lock. A logical sign reversal stops every motor,
waits 15 ms, and applies the new directions together. A separate watchdog thread
stops all output after 500 ms without a control heartbeat. GPIO starts low and
is forced low again during normal shutdown and handled Python exceptions. A
physical main cutoff remains required because software cannot guarantee safety
through OS lockups, regulator faults, broken wiring, or failed power electronics.

## Files that updates can and cannot change

```text
~/.local/share/motionmodule/
├── current -> releases/main-...        # service follows this link
├── previous -> releases/v0.1.0-...
└── releases/                            # immutable installed copies

~/MotionModule/active -> Mecanum/        # selected robot project
~/MotionModule/Mecanum/                  # persistent student-owned code
~/MotionModule/Swerve/                   # another possible robot project
~/.config/motionmodule/config.toml      # persistent hardware calibration
```

Installing a new Git tag/ref builds and tests a new release before switching
`current`. It does not pull in the background and does not overwrite student
code/config. `motionmodule rollback` swaps `current` and `previous` and restarts
the service. Rollback changes the backend runtime, not student files; students
should also use Git in `~/MotionModule` when they need revisions of robot code.
The stable service launcher detects releases from before Dashboard 0.2.0 and
runs their original project-hosted server, so Nginx and explicit rollback stay
compatible across that boundary.

## Connectivity choice

Systemcore's strongest usability idea is that deployment works over USB,
Ethernet, or Wi‑Fi with a stable network identity. For an ordinary Raspberry Pi,
Ethernet/Wi‑Fi SSH provides that same editing surface without a custom desktop
toolchain:

- VS Code Remote‑SSH edits and runs code directly on the Pi;
- mDNS supplies a friendly `motionmodule.local` address;
- Ethernet is available for reliable bench work;
- a root-owned NetworkManager helper exposes only fixed scan/connect/hotspot
  actions to the browser service;
- `motionmodule-network.service` waits 30 seconds for client Wi-Fi, then creates
  a direct robot hotspot when no LAN exists;
- the robot browser UI uses the same address and requires no app installation.

```text
boot
  |
  v
saved Raspberry Pi Imager / preferred Wi-Fi ---- connected ----> .local + DHCP IP
  |
  | no connection for 30 seconds
  v
MotionModule hotspot ----> http://10.42.0.1
```

Nginx is the stable front door on port 80, so a beginner can enter the bare Pi
IP or `.local` name. The dashboard application listens on port 8080 behind that
proxy and owns the live APIs. It is packaged with each versioned release; the
student drive hook is loaded from the persistent project.

## Source and robot-project boundaries

The Git repository has one central `MotionModule/` system directory. Its
`core/motion_module/` package owns hardware access, safety, the dashboard, and
network APIs. Direct sibling folders containing `robot.py` are robot projects;
`Mecanum` is the included example, not part of the core.

During installation, every bundled robot project is copied once into
`~/MotionModule/`. The `active` symlink selects the folder loaded by systemd.
`motionmodule project PROJECT_NAME` switches that symlink and restarts the
service. Runtime upgrades never overwrite those persistent project folders.

The hotspot profile has autoconnect disabled. A manual hotspot therefore stays
active for the current boot, while a reboot always gives saved client Wi-Fi the
first 30-second opportunity. Network changes are queued after an HTTP response
and stop all motor output before the adapter changes roles.

Bluetooth serial and automatic USB gadget mode were intentionally left out.
They add platform-specific pairing/drivers and provide a worse beginner coding
experience than SSH. USB Ethernet gadget support can be added later for a
specific Pi model without changing the Python hardware API.

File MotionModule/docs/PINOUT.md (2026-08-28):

# MotionModule pinout and power wiring

Software uses **BCM GPIO numbers**. Connector diagrams use **physical header
numbers**. Every table below shows both; never assume they are interchangeable.

## Four dual H-bridge boards

Each GODIYMODULES board controls two motors and has four signal inputs. Connect
each motor only to its own output pair. The names `IN1`/`IN2` below mean the two
direction inputs for that motor; match them to the board's A/B input labels.

| Driver | Output | Motor channel | Default use | IN1 | IN2 | Pi ground |
| ---: | :---: | ---: | --- | --- | --- | --- |
| 1 | A | 3 | Front right | physical 38 / GPIO20 | physical 40 / GPIO21 | physical 39 |
| 1 | B | 4 | Rear right | physical 37 / GPIO26 | physical 33 / GPIO13 | physical 39 |
| 2 | A | 1 | Front left | physical 32 / GPIO12 | physical 31 / GPIO6 | physical 34 |
| 2 | B | 2 | Rear left | physical 35 / GPIO19 | physical 36 / GPIO16 | physical 34 |
| 3 | A | 5 | Extra motor A | physical 29 / GPIO5 | physical 22 / GPIO25 | physical 20 |
| 3 | B | 6 | Extra motor B | physical 21 / GPIO9 | physical 23 / GPIO11 | physical 20 |
| 4 | A | 7 | Extra motor C | physical 24 / GPIO8 | physical 26 / GPIO7 | physical 25 |
| 4 | B | 8 | Extra motor D | physical 16 / GPIO23 | physical 18 / GPIO24 | physical 25 |

Drivers 1 and 2 preserve the supplied physical pin 30–40 block. Physical pin
30 is another available Pi ground but is not required by the reference harness.
Drivers 3 and 4 use the safe signals in physical pins 20–29, plus pins 16 and
18. There are not eight usable signals in 20–29 alone:

| Physical pin | Function in this design |
| ---: | --- |
| 20 | Ground — Driver 3 reference |
| 21 | GPIO9 — Driver 3 B IN1 |
| 22 | GPIO25 — Driver 3 A IN2 |
| 23 | GPIO11 — Driver 3 B IN2 |
| 24 | GPIO8 — Driver 4 A IN1 |
| 25 | Ground — Driver 4 reference |
| 26 | GPIO7 — Driver 4 A IN2 |
| 27 | GPIO0 / ID_SD — **leave disconnected** |
| 28 | GPIO1 / ID_SC — **leave disconnected** |
| 29 | GPIO5 — Driver 3 A IN1 |

This direct-GPIO profile intentionally supports four dual drivers/eight motors.
Adding still more direct H-bridges would consume pins reserved for other Pi
interfaces and increase boot-state/PWM complexity. Expand servos freely by I2C;
for more than eight brushed motors, add an addressed motor-control/PWM expansion
board and a new software backend instead of casually taking the ID or UART pins.

GPIO7/8/9/11 normally have alternate SPI functions. The reference Raspberry Pi
OS image has SPI disabled. `motionmodule doctor` warns if a `/dev/spidev*`
device is active; disable SPI before using Drivers 3 and 4.

Install a 10 kΩ pull-down resistor from every one of the 16 driver inputs to
signal ground, preferably at the driver connector. Raspberry Pi GPIOs are inputs
during early boot and cannot be relied on to hold an H-bridge input low until
Linux and the service have started. Keep motor power physically switched off
during boot until these pull-downs and the stopped-output behavior are verified.

## PCA9685 servo controller

The servo board is a separate I2C device and shares no motor GPIO.

| PCA9685 connection | Raspberry Pi / supply connection |
| --- | --- |
| SDA | physical pin 3 / GPIO2 |
| SCL | physical pin 5 / GPIO3 |
| VCC (logic) | physical pin 1 / 3.3 V |
| GND | physical pin 6 / ground |
| V+ screw terminal | separate regulated servo supply positive |
| V+ screw terminal GND | servo supply negative and common logic ground |

> [!WARNING]
> `VCC` powers PCA9685 logic. `V+` powers the servos. Do not bridge them and do
> not power a bank of servos from a Raspberry Pi 5 V header pin.

The first board has every address pad open and uses `0x40`. To add another
board, solder A0 on the second board for `0x41`, chain SDA/SCL/VCC/GND, provide
appropriately sized servo power, and edit:

```toml
[servos]
addresses = [0x40, 0x41]
```

Code then uses `module.servo(channel=0, board=1)` for the second board. Never
put two boards with the same address on one bus. The hardware can address many
boards, but wire length, bus capacitance, connector current, and power
distribution become the practical limits well before the advertised maximum.

## Power boundaries

Use three planned power domains:

1. Raspberry Pi logic power from a stable Pi-rated 5 V regulator.
2. Motor power from the robot battery through a main switch and correctly sized
   fuses to each driver branch.
3. Servo power from a separate regulated rail set for the connected servos,
   normally 5–6 V for standard hobby servos.

Join their negatives at a deliberate common reference point so 3.3 V control
signals have a return path. Do **not** route motor current through a Pi ground
pin: the heavy driver power negatives return directly to the battery/power
distribution bus, while the Pi ground wires are only low-current signal
references.

The Amazon listing's 10 A figure does not override a motor's stall-current
requirement. Measure or obtain each motor's stall current, fuse below the safe
wire/connector/driver limit, and add the recommended heat sinking/airflow for
high continuous current. Use one motor per H-bridge channel.

## First electrical test

1. Disconnect battery and servo power.
2. Verify every BCM/physical pin against the tables with a continuity meter.
3. Verify no motor supply positive is connected to a Pi header pin.
4. Set the servo regulator voltage before attaching servos.
5. Put the chassis on a stable stand with all wheels clear.
6. Confirm every driver input has its 10 kΩ pull-down, power the Pi first, and
   run `motionmodule doctor`.
7. Apply motor power with the physical cutoff in reach.
8. Stop the service and pulse one channel: `motionmodule stop`, then
   `motionmodule test-motor 1`.
9. Test each channel and label the resulting physical wheel/mechanism.
10. Restart normal code only after the map is verified: `motionmodule start`.

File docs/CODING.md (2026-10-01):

# Coding a MotionModule robot

Robot code is a normal local Python folder. You may use any text editor; the
only deployment tool is the robot's browser Driver Station.

## Start from the sample

1. Open `http://motionmodule.local/code` or the robot's IP in Chrome or Edge.
2. Press **Download Mecanum sample**.
3. Unzip it and rename the `Mecanum` folder for the new robot.
4. Edit that folder locally.
5. Return to Code, choose the whole folder, confirm, and press **Deploy and
   run**.

The same upload works on the saved Wi-Fi, Ethernet, and the direct MotionModule
hotspot. The local folder cannot move hardware. Only the validated copy sent to
the Pi runs.

## What goes in the folder

```text
MyRobot/
├── robot.py       # required: creates the browser drive controller
├── test.py        # optional: Debug Drive Test motor/servo mapping (Mecanum by default)
├── hardware.py    # optional: your own names, pins, inversion, servo boards
├── sensors.py     # MPU6500 wired directly to the Pi
├── autonomous.py  # optional: the routine the robot runs by itself
├── dashboard.py   # optional: Driver Station cameras, sensors, keys, sticks
└── helpers.py     # optional: any other Python files you want
```

Only `robot.py` is required. A folder without `hardware.py` runs on the
installed hardware map, whose names describe the hardware position
(`driver_1a`…`driver_4b` for the eight motor outputs, `servo_0`…`servo_15`
for the servo channels). They are listed in **Debug → Wiring**, and the
dashboard shows whatever names the running hardware map defines.

Add `hardware.py` when this robot needs its own names or wiring. Download the
current one from Debug or Code, rename the outputs you use, and keep it next to
`robot.py`. It must contain a single literal dictionary assignment:

```python
HARDWARE = {
    "module": {"pwm_hz": 1000, "deadtime_ms": 15, "watchdog_ms": 500},
    "motors": {
        1: {
            "name": "front_left",
            "forward_gpio": 26,   # physical pin 37
            "reverse_gpio": 19,   # physical pin 35, right next to it
            "inverted": False,
        },
    },
    "servos": {
        "enabled": True,
        "i2c_bus": 1,
        "frequency_hz": 50,
        "addresses": [0x40],
        "minimum_pulse_us": 500,
        "maximum_pulse_us": 2500,
    },
}
```

It may have a docstring and comments, but no imports, calls, calculations, or
other statements, so MotionModule can check the pins without running the file.
Debug reads whichever configuration is active to draw the wiring map and to
list the names available to your code.

`robot.py` defines the dashboard hook:

```python
from my_drive import MyDrive

def create_drive(module):
    return MyDrive(module)
```

The returned object implements:

```python
drive(forward, strafe, rotate, speed) -> dict
stop() -> None
```

Avoid permanent loops and hardware movement at module scope. MotionModule must
be able to import the project before it can serve the dashboard.

### Optional Debug Drive Test mapping

**Debug → Drive Test** loads `MyRobot/test.py`, next to `robot.py`. The sample
download includes this default file:

```python
from motion_module.mecanum import MecanumTestDrive

def create_test(module):
    return MecanumTestDrive(module)
```

No `test.py`? The same confirmed Mecanum test remains available. A present but
broken file disables Drive Test and displays its error; it never silently
substitutes another drive. After editing locally, deploy the whole robot folder
through Code to reload it. Existing customized projects are not overwritten by
an update; copy the sample's `test.py` into your folder when you want to customize it.

To test another drivetrain, return your own object with
`drive(forward, strafe, rotate, speed)` and `stop()`. The keys stay fixed:
W/S sends positive/negative `forward`, D/A positive/negative `strafe`, and Q/E
positive/negative `rotate`. Axes are clamped to −1…1 and speed to 0…1.
Use the supplied `module.set_motors(...)`, `module.motor(...)`, and
`module.servo(...)` APIs to map those inputs to motor/servo outputs; respect
the speed limit and stop on zero inputs. Return a JSON-compatible dictionary
or `None`. Tank code may ignore strafe; swerve code may command steering servos
as well as motors. These are output mappings, not changes to the shipped wiring.

Do not start loops/threads, move outputs while importing/constructing the
object, or open a second MotionModule. Each method must return promptly.
Space/Disable calls `stop()`, then forcibly stops **all** motors and releases
**all** servo pulses, even if your stop method fails. A command error or a
gap longer than the configured watchdog also stops/releases test outputs.
Keep Space as a safety stop, not an actuator command. Releasing servo pulses
does not mechanically hold a loaded mechanism: support it safely before testing.

This file affects only Debug. The full Driver Station still uses `robot.py`
(or its explicitly selected confirmed Mecanum mixer). `dashboard.py` key and
stick layouts and autonomous code do not change Drive Test.

### Optional full Driver Station telemetry

**Debug → Drive Test** uses `test.py` or its Mecanum fallback, not `robot.py`.
**Open Driver Station** in the top navigation opens
`/driver-station`, the separate operator console that does. Put `dashboard.py` beside `robot.py` to add up to two camera feeds,
one gyro/IMU, up to 20 Raspberry Pi readings, and up to 20 readings per USB
sensor controller. MotionModule discovers it automatically; no import in
`robot.py` is required, and deleting the file does not affect driving.

Sensors are set up once, in `sensors.py`, and `robot.py` hands them to the
drive object. `dashboard.py` shows that same object, so the console always
displays what the robot code reads:

```python
from motion_module.telemetry import CameraFeed, TelemetryDashboard

FRONT_STREAM = ""  # e.g. http://motionmodule.local:1181/?action=stream

class MyDashboard(TelemetryDashboard):
    def __init__(self, module, drive):
        self.sensors = drive.sensors

    def cameras(self):
        # Naming one camera, with no URL, is enough - see below. A second
        # one is only ever added the same way, one more CameraFeed:
        #
        #     REAR_STREAM = ""
        #     return [
        #         CameraFeed("Front", FRONT_STREAM, connected=bool(FRONT_STREAM)),
        #         CameraFeed("Rear", REAR_STREAM, connected=bool(REAR_STREAM)),
        #     ]
        return [CameraFeed("Front", FRONT_STREAM, connected=bool(FRONT_STREAM))]

    def imu(self):
        return self.sensors.reading()

    def usb_controllers(self):
        return []  # No additional USB sensors declared

def create_dashboard(module, drive):
    return MyDashboard(module, drive)
```

Camera URLs must be relative browser paths or HTTP/HTTPS streams. The Driver
Station preserves square viewports and lets the operator show either feed or
both. Return live readings quickly from `snapshot()`/the group methods; the
page polls them at 4 Hz. Mark missing hardware `connected=False` so it is shown
as offline rather than as a valid zero.

By default only one camera is coded, and that is deliberate: `cameras()`
naming a camera with no URL, as above, does not leave it a permanent offline
placeholder. MotionModule looks for a USB-connected camera itself and streams
it, JPEG-encoded, matching it to that named slot - "Front" here - with no
external streamer and no more code. A second physical camera, beyond what you
named, still shows up on its own and brings up the Front/Both/Rear toggle,
generically named until you give it a `CameraFeed` of its own the same way;
plugging one in - or back in after it was unplugged - is picked up within a
few seconds either way. A slot that already has its own URL (an external
streamer's) is left exactly as given, and leaving `dashboard.py` out
entirely, or `cameras()` empty, still puts one camera tile up. Streaming a
USB camera this way needs `opencv-python-headless`, which the real Pi
dashboard installs on its own, quietly, the first time it finds a camera
project code did not already wire up an external streamer for - the tile
says so while that install runs, which can take a few minutes the very first
time. Without a network connection for that one-time install, or without a
camera plugged in, the tile stays a clearly labelled offline placeholder
instead of an error, and says what to run by hand
(`pip install opencv-python-headless`) if the automatic install failed. The
operator can also rotate any camera's view from the Driver Station itself, in
the browser, with a slider, a quick-rotate button, or by typing an exact angle
- that is a per-viewer display preference, not something `dashboard.py`
configures.

## Pi-connected MPU6500 IMU

The Mecanum setup uses one MPU6500 wired directly to the Pi. Follow the
[complete wiring plan](PINOUT.md#optional-mpu6500-six-axis-imu): VCC to
physical pin 17, GND to pin 6 and AD0 to pin 20, SDA to 11 (GPIO17) and SCL to 12
(GPIO18). Grounding AD0 selects address 0x68. The board must be in I2C mode (CS high); INT is left disconnected. The motor and PCA9685 wiring stays as shipped.

The Pi installer adds this under `[all]` in `/boot/firmware/config.txt` and
reboots. Add it manually only for a setup without the installer:

```ini
dtoverlay=i2c-gpio,i2c_gpio_sda=17,i2c_gpio_scl=18
```

The sample's `sensors.py` already opens the IMU through MotionModule:

```python
from motion_module.imu import IMUConfig

# IMUConfig configures the Pi-connected MPU6500.
imu = module.local_imu(IMUConfig("Main IMU", address=0x68))
heading = imu.heading() if imu is not None else None
```

`module.local_imu()` discovers the independent `i2c-gpio` adapter by name,
creates one `motion_module.pi_imu.LocalIMU` reader, checks both MPU6500
addresses (0x68 and 0x69), and closes the reader when the
module shuts down. It returns `None` in simulation or without the overlay;
it never falls back to the servo bus. Enable the overlay and restart after
rebooting. With the bus present but the sensor missing, the reader reports
it offline and retries. `smbus2` is included as a runtime dependency.

`imu.heading()` returns degrees from -180 to 180, increasing as the robot
turns left, or `None` until usable readings arrive. `imu.zero()` sets the
current heading to zero. `imu.reading()` supplies the Driver Station;
`connected`, `calibrated`, `pitch()`, `roll()`, `rate()` and `describe()`
provide status and other readings. Keep the robot still for initial gyro
calibration. The Pi fuses gyro and accelerometer readings for relative yaw;
the DMP is unused. Heading can drift over time, so zero it
before a run. Compass mode is unsupported for this driver. Mount +Y toward
the front and +Z upward to match the pitch/roll convention.

On an existing robot folder that you have customized, update its own
`sensors.py` declaration to `IMUConfig("Main IMU", address=0x68)`.
The installer preserves every existing robot folder, including untouched
samples, and saves a pre-update snapshot. Use the explicit Code-page sample
installation action if you want the current bundled declaration.

The only built-in IMU is MPU6500, with WHO_AM_I `0x70`. Unknown identities,
including MPU9255 `0x73`, are rejected before configuration writes. There is
no chip selector or legacy IMU driver. `module.local_imu()` without arguments
uses `IMUConfig()`; a custom name or alternate address uses the declaration
above. Old `GigaIMU(...)` imports and declarations in customized robot
folders still load (0.12.1 and later) and read the MPU6500, with a warning in
the service log; replace them with `IMUConfig(...)` when you next edit them. Arduino expansion uses declared
inputs and does not load Pi-side IMU drivers.

The sample shares this single reader between robot.py, autonomous.py and
dashboard.py. No other sensor is predeclared.

### Heading control (`motion_module.heading`)

The IMU heading loop uses `error = target - heading`, wrapped
to ±180° so the robot turns the short way, and `power = kP * error - kD * rate`,
with the gyro's measured turn rate as the brake. A turn is finished only once
the heading stays within the tolerance for `settle_seconds`. Tune the gains
for your robot using the defaults below as a starting point.

```python
from motion_module.heading import HeadingController, HeadingHold, Settle

HEADING = HeadingController(kp=0.02, kd=0.001, max_power=0.5,
                            min_turn_power=0.2, tolerance=2.0, settle_seconds=0.1)
turn = HEADING.power(target, imu.heading(), imu.rate(), in_place=True)
```

`HeadingHold` is the Driver Station assist in the Mecanum sample. While the
driver turns, the driver is in charge; about 0.25 s after they let go it locks
the heading and corrects drift while the robot drives or strafes (never while
it stands still). `snap(heading, +1 / -1)` turns to the next multiple of 90°;
a second press stacks another 90°, and moving the turning stick cancels it. If
the heading runs away from the correction (a reversed turn direction, or a
stuck robot), holding switches itself off and says why.

Tuning, in `HEADING` in the sample's `robot.py`: lower `kp` or raise `kd` if
the robot wobbles or overshoots; raise `kp` if drift is corrected too slowly;
raise `min_turn_power` if turns stop a few degrees short. `min_turn_power` is
only used when turning on the spot from a standstill.

Zeroing is manual. `imu.zero(level=True)` makes the present direction 0° and
the present tilt level; nothing else re-zeroes it. The sample saves the level
in `.imu-level.json` beside `sensors.py`, so it survives a reboot. The heading
cannot: the MPU6500 has no compass, so after power-off it starts at 0° facing
wherever the robot faces. `imu.recalibrate()` measures the gyro at rest again
and keeps the heading. The gyro is also measured once at every start-up
(keep the robot still), because its resting error changes with temperature.

A key or game-controller button can press any of the drive's `controls()`
buttons: in `dashboard.py`, give the control's name as the action in
`driver_bindings()` (`{"turn_left_90": "z"}`) or `gamepad_buttons()`
(`{"left_bumper": "turn_left_90"}`). Each press sends the control once.

## Optional USB GPIO expansion

Additional sensors beyond the reference robot go through USB, directly or
through an **Arduino GIGA R1 WiFi** used for extra GPIO inputs. This is an
experimental extension, not a requirement for Mecanum; verify it with your
own hardware. The bundled firmware targets GIGA R1 WiFi, not Uno or Mega.

The existing bridge code discovers the GIGA by USB identity, opens its serial
port, sends your pin declarations on connection, and reconnects if unplugged.
It does not discover what is wired to the GPIO pins. Install its firmware
with `motionmodule giga flash`; see [setup](SETUP.md#optional-usb-gpio-expansion).

An opt-in extension can start empty:

```python
from motion_module.sensor_bridge import GigaPin

USB_PINS = []  # Add declarations only for additional inputs you actually wire.
expansion = module.giga(pins=USB_PINS)
# Once you add a declaration, read it by name with expansion.value(name).
# Expose expansion.snapshot() from dashboard.py's usb_controllers() method.
```

A declaration uses `GigaPin(pin, name, kind="digital", pull="none")`.
Digital pins D0-D75 read `True` or `False`; `pull` can be `"none"`, `"up"`
or `"down"`. Analog A0-A7 use `kind="analog"` and read 0-4095; optional
`scale`, `offset`, `unit`, `minimum` and `maximum` describe the reading.
Pins accept at most 3.3 V. `expansion.value(name)` returns `None` when no
fresh reading is available. This API reads inputs; it does not add motor
or servo outputs. Declare all inputs once and share the returned bridge.
MotionModule closes it at shutdown and never opens a physical board in simulation.

Leave the sample's USB controller list empty until you add an extension.
The IMU stays on the Pi; no Arduino IMU wiring is part of the reference setup.

## Motor API

Address a motor by its name, or by its channel number from 1 to 8:

```python
motor = module.motor("driver_3a") # module.motor(5) also works
motor.set(0.25)                   # -1.0 to +1.0
motor.stop()

module.set_motors({"driver_1a": 0.4, "driver_1b": 0.4, "driver_2a": -0.4, "driver_2b": -0.4})
module.stop_all()
```

`motor.name` and `motor.channel` tell you which output a handle refers to,
which is useful when printing debug output.

The controller clamps power, applies the `inverted` value from `hardware.py`,
inserts a coast interval before reversing, and stops stale output at the
watchdog deadline. A control routine must resend nonzero values faster than
that deadline.

## Servo API

```python
arm = module.servo("servo_0")     # module.servo(channel=0, board=0) also works
arm.set_angle(90)
arm.set_pulse_us(1500)
arm.release()
```

Each configured PCA9685 has channels 0–15. Verify the exact servo's voltage,
pulse range, mode, and mechanical clearance before commanding it. Use Debug's
guarded Servo Pulse Test for first movement.

The board's OE pin cuts all sixteen outputs at once, in hardware, so it still
works when the I2C bus does not:

```python
module.set_servo_outputs_enabled(False)   # every output off at the board
module.set_servo_outputs_enabled(True)
module.servo_outputs_enabled              # True while the outputs are live
```

`hardware.py` says which pin that is (`servos.output_enable_gpio`, GPIO4 by
default) or `None` if OE is left unconnected — in which case disabling raises
rather than pretending. The board pulls OE low on its own, so the outputs are
enabled whenever the Pi is not driving the pin. It is an enable line, not a
power cutoff.

Releasing servos and disabling them are separate on purpose: the Driver Station
sends a stop every time you leave the page, and cutting OE there would leave the
robot's servos dead after an ordinary navigation.

## Add mechanisms and sensors

Put robot-specific code in additional `.py` files inside the same folder:

```python
# mechanisms.py
class Intake:
    def __init__(self, module, name="driver_3a"):
        self.motor = module.motor(name)

    def run(self, power=0.35):
        self.motor.set(power)

    def stop(self):
        self.motor.stop()
```

Then import it with `from mechanisms import Intake`. USB or serial libraries
needed by a project must already be installed in the MotionModule runtime;
Debug's USB list only discovers attached devices and does not install drivers.

## What deployment validates

Before changing the active project, the Pi checks:

- one folder with a safe 1–64 character project name;
- `robot.py` at the top level;
- only `.py`, `.ino`, `.md`, and `.txt` files, up to 250 files and 8 MiB total;
- valid syntax in every Python file;
- a synchronous top-level `create_drive(module)` function;
- a synchronous top-level `create_dashboard(module, drive)` when a named
  `dashboard.py` is present;
- and, when the folder includes `hardware.py`, literal-only data with valid
  GPIOs, unique motor pins, unique names, allowed I2C addresses, pulse limits,
  and watchdog limits.

It then stops outputs, backs up an existing same-named folder, replaces it,
switches `~/MotionModule/active`, and restarts. If the new project later fails
while importing a dependency, open Debug's service log and correct the local
folder before deploying again.

## Autonomous

`autonomous.py` is optional. Without it the Driver Station simply has no
autonomous mode; with it, an **AUTONOMOUS** button appears beside
**TELEOPERATED** and **RUN AUTO** starts the routine.

```python
# autonomous.py
import time

class MyAuto:
    duration_seconds = 15.0     # None for no limit

    def __init__(self, module, drive):
        self.module, self.drive = module, drive

    def run(self, stop):
        deadline = time.monotonic() + 1.5
        while time.monotonic() < deadline:
            if stop.is_set():
                return
            self.drive.drive(1, 0, 0, speed=0.3)
            time.sleep(0.05)

def create_autonomous(module, drive):
    return MyAuto(module, drive)
```

A routine short enough not to need a class can be a bare
`run(module, stop)` function instead.

Three things are worth knowing:

- **An autonomous step is a loop, not one call and a sleep.** The motor
  watchdog stops the robot when commands stop arriving, so keep sending while
  the step lasts.
- **`stop` is a `threading.Event`.** Check `stop.is_set()` inside every wait and
  return as soon as it is set. Pressing DISABLE, the stop key, STOP, leaving the
  page, or losing the link all set it — and all stop every output immediately,
  whether or not your code has noticed yet.
- **The run is bounded.** `duration_seconds` (30 s by default) cuts off a
  routine that never returns; the page reports it as cut short. Set it to `None`
  to remove the limit, and then only DISABLE ends a routine that loops forever.

While autonomous is running, manual drive commands are refused rather than
queued, so the driver and the routine can never fight over the motors.

## The Driver Station's controls

The competition console's controls belong to the robot, so they come from
`dashboard.py`. A computer drives with the keys, or a game controller when one
is plugged in. A phone or tablet drives with two on-screen sticks instead: the
page shows them on a touch-first device, or as soon as the screen is touched,
and brings the keys back when a bound key is pressed. Every method below is
optional, and each returns only what you want to change.

### Keys

```python
def driver_bindings(self):
    return {"turn_left": "z", "turn_right": "c", "stop": "Escape"}
```

Anything left out keeps its default — W/S drive, A/D strafe, Q/E turn, space
disables and stops. A single character is matched without case; a named key
such as `ArrowUp` or `Escape` is matched as the browser reports it. If you bind
a key another action already owns, that other action is left unassigned rather
than one key meaning two things.

### Game controller and touch sticks

`gamepad_sticks()` says which game-controller stick drives, strafes and turns;
`touch_sticks()` says the same for the on-screen sticks. Both name the same
four axes, `left_x`, `left_y`, `right_x` and `right_y`:

```python
def gamepad_sticks(self):
    # A tank drive: left stick forward and back, right stick turns.
    return {"strafe": None, "deadzone": 0.15, "curve": 2}

def touch_sticks(self):
    # One stick to drive, and Turn left / Turn right buttons to turn.
    return {"rotate": "buttons"}
```

| Key | Default | What it does |
| --- | --- | --- |
| `forward` | `"left_y"` | Pushing this axis up drives forward |
| `strafe` | `"left_x"` | Pushing this axis right strafes right |
| `rotate` | `"right_x"` | Pushing this axis right turns right; the touch sticks also take `"buttons"` |
| `deadzone` | `0.12` controller, `0.1` touch | How far a stick moves, from 0 to 0.5, before it counts |
| `curve` | `1.0` | Above 1, up to 3, gives finer control near the middle |

Put `-` in front of an axis to flip it (`"-left_y"`), or use `None` to switch a
motion off. One axis never moves the robot two ways: if you give a motion an
axis another motion has by default, that other motion is switched off. On the
screen, a stick given two motions moves all the way round and a stick given one
moves only that way, so by default the left stick drives and strafes and the
right stick only goes left and right. Whatever the layout, the numbers reach
`drive()` exactly as the keys' do, from -1 to 1.

A touched stick centres itself under the thumb, so touching down never moves
the robot; dragging does, and lifting the thumb stops it at once. A thumb that
was on a stick when the robot was disabled does nothing until it lifts and
touches again. A held key wins over the sticks, and the sticks over a game
controller.

### Game controller buttons

`gamepad_buttons()` says which buttons trigger an action, as `{button:
action}`:

```python
def gamepad_buttons(self):
    return {"left_bumper": "turn_left", "right_bumper": "turn_right"}
```

The buttons are `a`, `b`, `x`, `y`, `left_bumper`, `right_bumper`,
`left_trigger`, `right_trigger`, `dpad_up`, `dpad_down`, `dpad_left` and
`dpad_right`. The actions are the same six `drive()` directions as
`driver_bindings` (`forward`, `back`, `left`, `right`, `turn_left`,
`turn_right`), plus `stop` and `estop`, either of which disables the robot
the instant the button goes down — the controller's own STOP button. A
button held down drives like a held key, at full speed, and wins over that
motion's stick reading. Return only what you want to change: by default the
D-pad's down button is `stop` and the right trigger is `estop`; give a
button `None` to unbind a default without replacing it.

### Touchscreen panels

A phone or tablet shows only robot control, the sticks and the cameras. Turned
on its side, a phone keeps the sticks under the thumbs in the bottom corners.
`touch_panels()` adds any of the other panels:

```python
def touch_panels(self):
    return ["mechanisms", "imu"]
```

The names are `status` (the four status lights), `mechanisms`, `imu`,
`pi_inputs` and `usb_controllers`. A computer always shows every panel.

None of this changes **Debug → Drive Test**, which keeps fixed W/S, A/D, Q/E
and Space keys. Change its motor/servo mapping in `test.py`, not its keys.

## Manual testing

The shipped Mecanum `robot.py` uses `motion_module.mecanum.mix`, shared with
the default **Debug → Drive Test**, so it includes the same physically confirmed turning
correction. Use that mixer when extending this robot rather than maintaining
another copy of its wheel equations. It returns normalized powers keyed by
channels 1–4; motor polarity remains in `hardware.py`.

The Driver Station's **Use confirmed Mecanum mixer** selects that same built-in
movement for manual commands without editing the project's files. It defaults
on for a project named `Mecanum`, off for other projects. Uncheck it to call
your own drive method. Changing it disables and stops outputs, requiring a
fresh enable. Project controls, telemetry, and autonomous routines still run
their own code; this selector only changes the keyboard/gamepad movement path.

With that option unchecked, the **Driver Station** calls your `drive()` method, from the keyboard, a
game controller or the touch sticks. All three send the same `forward`, `strafe`
and `rotate` numbers, so code written for one works with the others. Keys and
sticks are laid out in `dashboard.py`; see
[The Driver Station's controls](#the-driver-stations-controls).

Drive works only while its deliberate-enable box is ticked. Releasing keys or
sticks, the stop key, STOP, leaving the page, or losing communications produces a stop, and
a lost connection also disarms the box so you have to re-arm on purpose. The
hardware watchdog is the final backstop.

While armed, the page sends a command on every tick, including zeros. Letting go
of a key therefore reaches `drive()` as `0, 0, 0` on the next frame rather than
waiting for the watchdog, so a tap is a tap. Your `drive()` is called at roughly
12 Hz whether or not anything is moving; keep it cheap and free of blocking
calls.

A drive object may also declare extra buttons and sliders, which appear in the
full Driver Station:

```python
def controls(self):
    return [{"name": "intake", "label": "Intake", "kind": "hold"}]

def control(self, name, value):
    if name == "intake":
        self.module.motor("driver_3a").set(value)
```

Keep a physical power cutoff in reach. First verify every raw output using
Debug with the chassis raised, then test the project's drive mapping slowly.

### Live IMU axes and USB topology

The Driver Station and Test outputs IMU panels include sensor X/Y/Z
accelerometer readings in g (including gravity) and bias-corrected gyro
readings in degrees/second. `IMUReading` exposes `acceleration_g` and
`gyro_dps` as optional three-axis tuples. Missing or stale readings display
a dash. Calibrating orientation does not subtract gravity from acceleration.

Only the MPU6500, reporting WHO_AM_I 0x70 at address 0x68 or 0x69, is
supported. Other chip identities are rejected before configuration writes.
The reader does not initialize or read a magnetometer.

Checks & logs separates Linux USB root hubs from attached devices. It shows
host ports, their bus paths, and downstream hub ports, including empty ones.
Linux sysfs `peer` links combine USB 2 and USB 3 paths sharing one socket;
without that metadata, logical ports remain separate rather than guessing a
physical location. These paths do not imply a top/bottom label on the case.

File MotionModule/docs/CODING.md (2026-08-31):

# Coding robots on MotionModule

The system dashboard loads exactly one active robot project's drive hook:

```text
~/MotionModule/active/robot.py
```

The starter file defines:

```python
from mecanum import MecanumDrive

def create_drive(module):
    return MecanumDrive(module)
```

The returned object implements `drive(forward, strafe, rotate, speed)` and
`stop()`. `module` is the hardware controller. MotionModule owns the web server,
network setup, and cleanup, so runtime updates do not overwrite the student
folder. Existing projects with the original `MecanumDrive` class remain
compatible even when they do not yet define `create_drive`.

## Robot project folders

`Mecanum` is one example, not a required drivetrain. Create any direct folder
under `~/MotionModule` and give it a `robot.py`:

```text
~/MotionModule/
├── Mecanum/robot.py
├── Swerve/robot.py
├── WalkingRobot/robot.py
└── active -> Mecanum/
```

The drive object returned by `create_drive(module)` can implement Mecanum,
swerve, tank, walking, or another mechanism. It only needs `drive(...)` and
`stop()` methods compatible with the dashboard controls. List and switch
projects with:

```bash
motionmodule project list
motionmodule project Swerve
```

The switch restarts the service. Hardware configuration remains shared at
`~/.config/motionmodule/config.toml`; project code remains independent.

## Motors

Channels are 1 through 8:

```python
intake = module.motor(5)
intake.set(0.30)   # -1.0 to +1.0
intake.stop()
```

For coordinated motion, update channels together. This gives every reversing
channel one shared coast/deadtime interval:

```python
module.set_motors({1: 0.4, 2: 0.4, 3: 0.4, 4: 0.4})
```

Any nonzero motor output arms the watchdog. Refresh with another motor command
or `module.feed_watchdog()` within 500 ms. A stale controller stops all motors.

## Servos

PCA9685 boards count from zero. Each board has channels 0 through 15:

```python
claw = module.servo(channel=0, board=0)
claw.set_angle(30)
claw.set_angle(110)
claw.release()
```

`release()` turns that PWM output fully off; it does not physically move the
servo to a safe pose first. Code the safe pose for the actual mechanism, wait
for motion, then release if the mechanism should not hold torque.

## Mecanum math and the turning fix

The example treats physical/electrical motor direction and chassis kinematics as
separate layers. The standard normalized wheel equations are:

```text
front_left  = forward + strafe + rotate
rear_left   = forward - strafe + rotate
front_right = forward - strafe - rotate
rear_right  = forward + strafe - rotate
```

A pure rotation therefore drives both left wheels together and both right
wheels in the opposite direction. The earlier City Tech version mixed the
front wheels against the rear wheels and tried to account for installed motor
orientation inside the math; that can produce diagonal/translation behavior
instead of a center turn. The default config now marks the installed first four
motors as inverted, so the mixer remains conventional and testable.

If a wheel is wrong, calibrate its `inverted` setting. If the robot turns the
opposite named direction but otherwise rotates correctly, swap the Q/E mapping
or invert the `rotate` command once at the control boundary.

## Running without hardware

On any development computer:

```bash
cd MotionModule
python -m venv .venv
# Windows: .venv\Scripts\activate
# Linux/macOS: source .venv/bin/activate
python -m pip install -e .
python -m unittest discover -s tests -v
```

Non-Pi computers automatically simulate GPIO and PCA9685 state. On a Pi, set
`MOTIONMODULE_MOCK=1` before a manual run to avoid touching hardware.

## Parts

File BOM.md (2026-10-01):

# MotionModule bill of materials

The reference hardware for one eight-motor, sixteen-servo MotionModule robot.
The whole machine runs from a **single 12 V battery**: the motor drivers take
that 12 V directly, the Raspberry Pi gets 5 V from a USB-C converter, and the
servos get their own regulated rail.

The same list is built into the dashboard under **Debug → Parts list**, so it
works on the robot hotspot with no internet connection. Both enclosure CAD
entries have **Download STEP CAD** links; the STEP files ship with the controller
and download directly from it, without a GitHub redirect.

**The first two sections are the robot.** Buy those and MotionModule boots,
serves its dashboard and drives outputs. Everything after them — motors,
servos, wire — is a recommendation, not a requirement.

---

## Required · Controller and control boards

| Qty | Part | Selection | Purpose |
| ---: | --- | --- | --- |
| 1 | Raspberry Pi 5 | 40-pin GPIO header; 4 GB is sufficient | Runs MotionModule, the dashboard, Wi-Fi, and robot code |
| 1 | microSD card | 32 GB or larger, Application Performance Class A2 recommended | Raspberry Pi OS and versioned releases |
| 1 | Pi 5 active cooler | [Argon THRML 30 mm active cooler](https://argon40.com/products/argon-thrml-30mm-active-cooler) | Prevents thermal throttling in an enclosed robot |
| 4 | Dual H-bridge motor driver | [GODIYMODULES DC 3–18 V, dual H-bridge PWM driver](https://www.amazon.com/dp/B0FKH352D2) | Two brushed motors per board; eight channels total |
| 1 | 16-channel servo controller | [AITRIP PCA9685](https://www.amazon.com/dp/B07WS5XY63) at address `0x40`, all pads open | Sixteen servo PWM channels over I²C |
| 1 set | Controller mounting CAD | [motion-module.step](cad/motion-module.step) | Printable mounts holding the Pi, drivers and servo board together |
| 1 assortment | Self-tapping screws | [Fasvicna M1.7–M3, 750-piece assortment](https://www.amazon.com/dp/B0H8CK9QVW); use 4 × M2.3 × 5 mm and 22 × M3 × 5 mm | Mounts the Pi, motor drivers, servo board and IMU, and secures the motion-module enclosure plates |

### Motion-module mounting screws

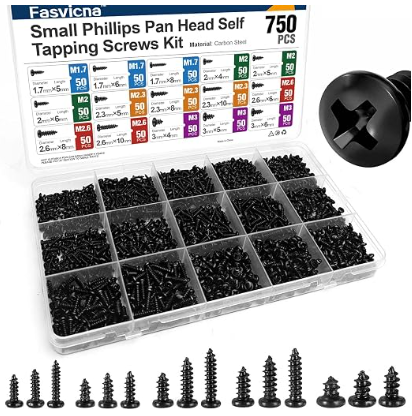
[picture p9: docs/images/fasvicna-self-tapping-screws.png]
Fasvicna self-tapping screw assortment


Use the self-tapping screws from the assortment for the supplied enclosure:

The complete assembly needs **4 M2.3 × 5 mm screws and 22 M3 × 5 mm screws**
in total, including the IMU and the four enclosure corner screws.

| Mounting location | Screw size | Quantity |
| --- | --- | --- |
| Raspberry Pi | M2.3 × 5 mm | 4 |
| Four motor-driver boards | M3 × 5 mm | One per board mounting hole |
| PCA9685 servo board | M3 × 5 mm | One per board mounting hole |
| IMU | M3 × 5 mm | One per board mounting hole |
| Top plate to bottom plate | M3 × 5 mm | 4, one at each corner |

The PCA9685 confirms over I²C that its logic is present, but it cannot report
whether an individual servo is plugged into an output. The H-bridge inputs have
no return path at all, so a configured motor channel is never proof of a
connection.

### Recommended · Pi-connected MPU6500

The Mecanum robot's IMU connects directly to the Pi on the independent
`i2c-gpio` bus. No Arduino is needed for the reference robot.

| Qty | Part | Selection | Notes |
| ---: | --- | --- | --- |
| 1 | MPU6500 gyroscope + accelerometer | [Reference IMU module](https://www.amazon.com/dp/B0GTVCCY6B) | Six-axis IMU; read by the Pi at 0x68; required chip identity 0x70. Seller titles may say MPU9255. |

VIN goes to physical pin 17, GND to 20, SDA to 11, SCL to 12, and AD0 to 6.
Use the [complete wiring guide](docs/PINOUT.md#optional-mpu6500-six-axis-imu)
and [Pi IMU setup](docs/CODING.md#pi-connected-mpu6500-imu). The robot can drive
without the IMU, but heading will be unavailable.

## Required · Power module

| Qty | Part | Selection | Status |
| ---: | --- | --- | --- |
| 1 | 12 V battery | [goBILDA 12 V NiMH, 3000 mAh, XT30](https://www.gobilda.com/12v-nimh-nested-battery-3000mah-mh-fc-xt30-connector/) | Selected |
| or | 12 V battery | [REV 12 V Slim, 3000 mAh, XT30](https://www.revrobotics.com/rev-31-1302/) — inline 20 A replaceable ATM fuse | Selected |
| 1 pack | XT30 pigtails | [XT30 male & female leads on silicone wire](https://www.amazon.com/dp/B0FY2ZCR83) | Selected |
| 1 | 12 V → 5 V USB-C converter | [Amazon B0FD735LFG](https://www.amazon.com/dp/B0FD735LFG) | Selected |
| 1 | Rocker switch | [DaierTek KCD1 automotive rocker switch](https://www.amazon.com/DaierTek-Listed-Switches-Automotive-KCD1-5Pack/dp/B07S1MV462) | Selected |
| 1 | 12 V/24 V → 5 V 5 A buck converter | [PlusRoc waterproof buck converter, 2-pack](https://www.amazon.com/dp/B0FYNCSV2Z) | Selected |
| 1 set | Power module CAD | [electronics-box.step](cad/electronics-box.step) | Included STEP model |

**Both batteries ship with their own fuse**, so there is no separate fuse or
breaker to buy. The rocker switch is the physical cutoff. **The buck converter
above steps the 12 V battery rail down to the PCA9685's servo V+ terminal**,
which is rated 3.3–6 V; the converter's fixed 5 V output sits safely inside
that range. It outputs 5 A (25 W) maximum — size how many servos you run at
once against that budget.

> [!WARNING]
> **V+ feeds every servo directly.** The board will take up to 12 V there, but
> hobby servos want 5–6 V and an Axon Mini MK2 tops out at 8.4 V, so give V+ the
> stepped-down rail rather than the battery. The **V+ header pin is the same net
> as the screw terminal**, so it already carries the servo rail — wiring it to a
> Pi 5 V pin would put that rail straight into the Pi. Neither the 12 V rail nor
> the servo V+ rail may touch a Raspberry Pi header pin; the Pi is powered only
> through its USB-C input.

---

## Recommended · Motors and servos

None of this is needed to make the controller run. These are the parts known to
work well on it.

| Qty | Part | Selection | Notes |
| ---: | --- | --- | --- |
| Up to 8 | Brushed DC motors | [goBILDA Yellow Jacket planetary gear motors](https://www.gobilda.com/yellow-jacket-planetary-gear-motors) | What we run. **Any brushed DC motor rated for 12 V works** |
| Up to 8 | 3.5 mm bullet lead, MH-FC to bare wire | [goBILDA GB-3800-0013-0300](https://www.gobilda.com/3-5mm-bullet-lead-mh-fc-300mm-length/), 300 mm, 16 AWG | Bullets plug onto the motor; the bare end screws into the driver's terminal block |
| Up to 16 | Servo | [goBILDA Axon Mini MK2](https://www.gobilda.com/axon-mini-servo-mk2/) | **Recommended.** Any Axon servo is a step up: programmable range, mode and centring |
| Alternative | Servo | [Standard three-pin servos](https://www.gobilda.com/standard-size-servos) | Any standard 3-pin hobby servo works; match its voltage to the servo rail |

Each dual H-bridge board is rated **10 A in total, shared between its two
outputs** — that budget covers both motors on the board, not 10 A each. Size
the motors so two of them together stay inside it.

**Motor connectors.** Yellow Jacket motor leads end in 3.5 mm **FH-MC** bullets
(female housing, male contact), so the part that mates with them is the
**MH-FC** lead above. Its bullets push onto the motor and its bare end goes
straight into the driver's screw terminal — no crimping, no adaptor. goBILDA's
*JST VH adaptor* converts those same bullets to a REV Expansion Hub connector
and is not used in this build. Swapping which bullet lands on which terminal
reverses that motor, but set direction with `inverted` in `hardware.py` rather
than in the wiring.

## Optional · USB GPIO expansion

| Qty | Part | Selection | Notes |
| ---: | --- | --- | --- |
| Optional | USB GPIO board | [Arduino GIGA R1 WiFi, ABX00063](https://store-usa.arduino.cc/products/giga-r1-wifi) | USB-C data cable to the Pi; GPIO inputs take 3.3 V maximum |

This is an experimental extension for future sensors, not part of the
Mecanum wiring. USB auto-detection, bridge firmware and a Python pin API are
included; operation with your hardware needs verification. No extra sensors
are selected or declared. The firmware targets GIGA, not Uno or Mega.
See [USB expansion setup](docs/SETUP.md#optional-usb-gpio-expansion).

## Recommended · Wiring

| Qty | Part | Requirement |
| ---: | --- | --- |
| As needed | Jumper wires | [Multicoloured breadboard jumper set](https://www.amazon.com/Elegoo-EL-CP-004-Multicolored-Breadboard-arduino/dp/B01EV70C78); female-to-female for the Pi header |
| As needed | Wago 221 lever connectors | [Wago 221-2401 compact splicing connectors](https://www.amazon.com/221-2401-Compact-Splicing-Inline-Connectors/dp/B0BT8DHLJJ) for every 12 V join |
| As needed | 16 AWG silicone wire | [Haerkn 16 AWG silicone wire, two cores, tinned copper, 25 ft](https://www.amazon.com/dp/B07RRPFL3Q) for the 12 V battery and motor runs, up to the 10 A each driver draws |

That is the whole wiring list. Control signals are ordinary jumper wires from
the Pi header, every 12 V and motor run is 16 AWG silicone wire, every 12 V
join is a Wago connector, and the boards, motors and servos all arrive with
their own leads. The wire's red core is positive and its black core negative.

Raspberry Pi GPIOs are inputs during early boot, so keep motor power switched
off until you have watched the outputs stay still. If one driver twitches at
boot, a 10 kΩ pull-down from that input to signal ground holds it low.

## Recommended · Tools for setup

- Digital multimeter with continuity and DC-voltage modes.
- Current-limited bench supply when available.
- Stable robot stand that keeps every wheel off the floor.
- Small screwdriver set and wire stripper.

---

## Enclosure CAD

Both STEP assemblies are included in [cad/](cad/README.md). The electronics
box fits either reference battery. Its switch-and-battery-lead section sits
beside a hollow compartment for the 12 V wiring; the reference robot hides
its buck converters and motor-driver power distribution inside that space.

The complete signal wiring is in [docs/PINOUT.md](docs/PINOUT.md).

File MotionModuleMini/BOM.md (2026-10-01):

# MotionModule Mini bill of materials

Four brushed-motor outputs, sixteen servo outputs and the Pi-connected MPU6500.
This list is also available offline in the Mini dashboard under Debug → Parts list.

| Quantity | Part | Selection |
| ---: | --- | --- |
| 1 | Raspberry Pi 5 | 4 GB is sufficient |
| 1 | microSD card | 32 GB or larger, A2 recommended |
| 1 | Active cooler | [Argon THRML 30 mm](https://argon40.com/products/argon-thrml-30mm-active-cooler) |
| 2 | Dual H-bridge motor driver | [GODIYMODULES DC 3–18 V](https://www.amazon.com/dp/B0FKH352D2); two motors per board |
| 1 | PCA9685 servo controller | [AITRIP PCA9685](https://www.amazon.com/dp/B07WS5XY63), 0x40, all address pads open; 16 servo outputs |
| 1 | MPU6500 IMU | [Reference module](https://www.amazon.com/dp/B0GTVCCY6B); same independent Pi I²C bus |
| 1 assortment | Self-tapping screws | [Fasvicna M1.7–M3, 750 pieces](https://www.amazon.com/dp/B0H8CK9QVW) |
| Up to 4 | Brushed 12 V motors | [goBILDA Yellow Jacket](https://www.gobilda.com/yellow-jacket-planetary-gear-motors), or another suitable 12 V brushed motor |
| Up to 4 | Motor bullet leads | [goBILDA MH-FC to bare wire](https://www.gobilda.com/3-5mm-bullet-lead-mh-fc-300mm-length/) |
| Up to 16 | Servos | Same servo choices and regulated power requirements as the full module |

Fasvicna self-tapping screw assortment

Use **four M2.3 × 5 mm self-tapping screws** for the Pi. Use **M3 × 5 mm**
for the two motor-driver boards, PCA9685 and IMU, one per mounting hole.
The Mini enclosure and its corner screw count must follow its final CAD;
the full enclosure's 22-M3-screw total is not a Mini specification.

Use the same [power module](../BOM.md#required--power-module): 12 V battery,
XT30 leads, cutoff switch, Pi USB-C converter, regulated 5 V / 5 A servo
converter and electronics box. The two driver boards each share a 10 A budget
between their two motor outputs. Servo current remains limited by the same
5 A converter. Keep motor and servo power away from Pi header power pins.

Use the same [wire, connectors and setup tools](../BOM.md#recommended--wiring).
Mini has no Drivers 3 or 4 and no motor channels 5–8. Mini enclosure CAD is not
included; the [power-box CAD](../cad/electronics-box.step) is still available.
See the [Mini pinout](PINOUT.md) before connecting the robot.

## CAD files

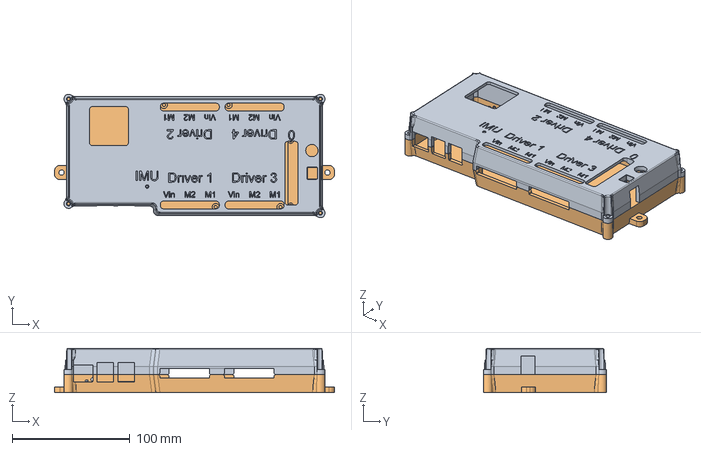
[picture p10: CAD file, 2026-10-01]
cad/motion-module.step
237.9 x 104.9 x 37.8 mm

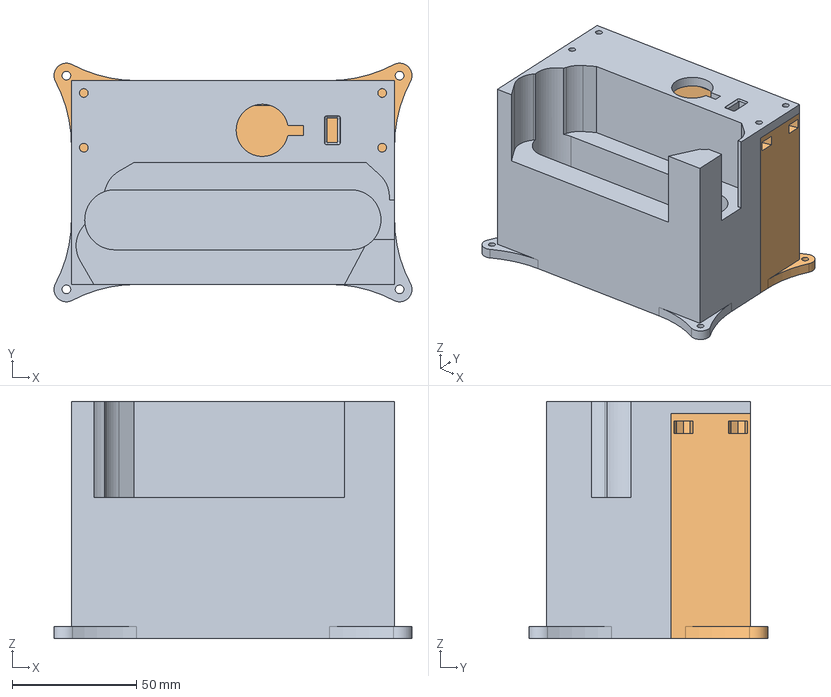
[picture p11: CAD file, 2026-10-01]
core/motion_module/static/cad/electronics-box.step
144.0 x 96.0 x 95.5 mm

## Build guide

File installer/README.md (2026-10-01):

# Installer behavior

## Upgrading to 0.12.1 (install this, not 0.12.0)

0.12.0 removed the old `GigaIMU` declaration. A robot folder that the
installer kept because it was edited could still import it, and then the
robot's web page would not start (nginx showed "502 Bad Gateway"). 0.12.1
fixes that, so skip 0.12.0 and install 0.12.1 or later:

- Old `sensors.py` files load again. `GigaIMU(...)` from `motion_module.imu`
  or `motion_module.sensor_bridge` now means the one built-in IMU, the MPU6500
  on the Pi, and the service log says so. `module.giga(imus=...)` is accepted
  and ignored; Arduino IMUs are no longer read and report no heading. No other
  IMU driver came back.
- Current installs keep every existing robot folder, including untouched
  samples, and save a pre-update code snapshot. Updating the bundled sample
  in an existing project is an explicit Code-page action.
- If a robot project still cannot load, the dashboard opens in **recovery
  mode** instead of failing. It shows the real error, stops every output,
  turns the servo outputs off and refuses driving, motor, servo and autonomous
  commands. Logs, Debug checks, Code → Deploy and Update keep working, so a
  fixed folder or a newer release can be installed from the browser.
- On a Raspberry Pi 5 the installer turns on the Pi's own fan control (see
  "Pi 5 fan cooling" below).

When you next edit a customized `sensors.py`, replace the old lines with:

```python
from motion_module.imu import IMUConfig
IMU = IMUConfig("Main IMU", address=0x68)
```

`module.local_imu(IMU)` and `module.local_imu()` both read the MPU6500.
Motor, PCA9685 and IMU wiring are unchanged (IMU GND on physical pin 6, AD0
on physical pin 20).

After installing and restarting, run Debug's checks, keep the robot still
until the Driver Station reports Ready, and zero heading. The software tests
simulate the IMU; confirm calibration, turn direction and live heading on the
physical robot before using IMU-guided driving.

For a source archive, extract it and run `bash install.sh` from the extracted
folder on the Pi. This installs the files in that folder. A wheel alone does
not include the installer, robot samples or Arduino firmware bundle.

## Pi 5 fan cooling

The Pi 5 active cooler plugs into the board's own four-pin FAN connector, not
the 40-pin GPIO header. On a Pi 5 the installer adds one marked `[pi5]` block
to `/boot/firmware/config.txt` (or `/boot/config.txt`) near the top, before
any `dtoverlay=` line, and keeps a dated backup of the file it changed:

| CPU temperature | Fan |
| --- | --- |
| below 47 °C | off (after running, it stops once below 45 °C) |
| 47 °C | approximately 75%, PWM 191 of 255 |
| 50 °C and above | 100%, PWM 255 of 255 |

These are the firmware's `cooling_fan` and `fan_temp0`-`fan_temp3` settings
(with 2 °C `_hyst` each), so the Pi's firmware and kernel run the fan. It keeps
cooling when MotionModule, the dashboard or the robot project is stopped or
broken. Running the installer again changes nothing; fan settings you wrote
yourself outside the block are left in charge. The change takes effect after
the reboot at the end of the install.

The dashboard's CPU temperature card and Debug checks show the temperature,
the fan level the kernel chose and, when the Pi reports it, the fan's RPM. A
fan that is off while the Pi is below 47 °C is normal. If the Pi is hot and the
fan is asked to run but stays still, switch the Pi off, check the fan's small
plug is pushed fully into the FAN connector, and power on again.

## Running the installer

Run the repository entry point:

```bash
bash install.sh --hostname motionmodule-01
```

Or install a published ref:

```bash
curl -fsSL https://raw.githubusercontent.com/AloeVeraZ/MotionModule/main/install.sh | \
  bash -s -- --version main --hostname motionmodule-01
```

| Option | Meaning |
| --- | --- |
| `--version REF` | Explicit Git branch, tag, or fetchable commit |
| `--hostname NAME` | Set the Pi's mDNS/browser hostname |
| `--robot PROJECT` | Initial bundled example; defaults to `Mecanum` |
| `--no-hostname` | Preserve the current hostname |
| `--no-start` | Enable without starting services |
| `--no-reboot` | Skip the default final reboot |

The bootstrap downloads the requested ref to a temporary directory. The main
installer adds system dependencies, copies source into a new release, builds a
per-release virtual environment, runs the unit tests, and marks the release
complete. Only then does the `current` link change. Failure before activation
leaves the previous runtime selected.

## Installing replaces MotionModule

An install replaces the MotionModule software instead of adding a version next
to the old ones. That is what makes the `main` and `testing` branches
interchangeable: a Pi on either one can install the other, in either
direction, as often as needed.

```bash
motionmodule install testing   # from main
motionmodule install main      # back again
```

Once the new release is active and its service has stayed up for a few
seconds, the installer removes what older installs left behind:

- every other release in `~/.local/share/motionmodule/releases`;
- MotionModule scripts in `/usr/local/sbin`, sudo rules, systemd services,
  nginx sites, and udev rules that this version does not ship, disabling a
  stale service before deleting it;
- leftover upload archives and any temporary web terminal access code.

It never removes the robot's own files: the projects in
`~/MotionModule/robots`, their backups in `~/MotionModule/backups`, the
`active` project link, the pin names in `~/.config/motionmodule/hardware.py`
(and an older `config.toml`), or the Wi-Fi, hotspot, and hostname settings.

Two releases can remain after an install:

- When the release it replaced came from the same branch, tag, or commit, that
  release stays as the offline `motionmodule rollback` target. A release from
  another branch is always removed, so branches never mix.
- When the new service could not be confirmed running (it crashed, or
  `--no-start` was used), the release it replaced stays, whatever branch it
  came from, as the way back. The next install removes it.

`motionmodule install REF` downloads that ref's own bootstrap, falling back to
`main`'s, so each branch installs with its own scripts even after they
change.

For optional Arduino GIGA R1 WiFi USB GPIO expansion, the installer also installs
`dfu-util`, adds the user to the `dialout` group (its USB serial port) and the
`plugdev` group, and writes `/etc/udev/rules.d/motionmodule-giga.rules`, which
lets that user flash the GIGA's firmware with `motionmodule giga flash`
without sudo. Reboot once after the first install so the groups apply.

Bundled examples are copied into `~/MotionModule/robots` on the first install.
Later installs keep every existing folder and its files, including unedited
samples, and snapshot robot code under `~/MotionModule/backups`. New sample code
is installed into an existing folder only with the explicit Code-page action.
The recognized retired pin map is still migrated to the locked wiring, with its
old file and a pre-update snapshot kept. The `active` symlink selects the
project loaded by the dashboard. A project may include its own data-only `hardware.py`;
otherwise the installed `~/.config/motionmodule/hardware.py` supplies the pins
and names. Installs made before that file existed keep using their
`~/.config/motionmodule/config.toml`.

The browser Driver Station accepts one local Python project folder. Deployment
validates paths, size, file types, Python syntax, `robot.py`, and any
`hardware.py`, stops output, backs up an existing target, installs it
atomically, switches
`active`, and cleanly restarts the service. Nginx allows the bounded multipart
upload and exposes the dashboard on port 80.

The installer also configures the root-owned constrained NetworkManager helper
and `motionmodule-network.service`. The helper records active Imager Wi-Fi.
After boot, saved networks receive 30 seconds to connect before the protected
fallback hotspot starts. Browser network changes invoke only fixed helper
actions.

The Code-page Bash terminal remains locked until the Pi user runs
`motionmodule terminal enable [MINUTES]` during an admin SSH session. Its
mode-0600 access grant is temporary and boot-scoped; the terminal receives no
extra sudo access.

After activation, the installer runs the non-moving Doctor check and reboots so
GPIO/I2C membership and boot configuration take effect. Its final printed
message is the GitHub pinout link. Use `--no-reboot` only when provisioning
still has more work to do.

No update service or timer is installed, and nothing installs itself. The
dashboard's update card reads `INSTALL_REF` and `INSTALL_COMMIT` from the
release root, compares them against `git ls-remote` for `main` and `testing`,
and, when you press the button, runs `/usr/local/sbin/motionmodule-update REF`
through the `motionmodule-update` sudoers rule. That helper starts a transient
`systemd-run` unit so the install survives its service restarts, logs to
`/var/log/motionmodule-update.log`, and leaves the installer's default final
Pi reboot enabled. The installer also recognizes that dedicated unit and
overrides the obsolete `--no-reboot` supplied by older dashboard helpers, so
the first update to this behavior reboots too. When `sudo` asks the Pi user for
a password, the dashboard asks for it, checks it with `sudo -S -k`, and passes
it to the helper on stdin. The helper keeps it in a root-only file under
`/run/motionmodule-update` while that update runs, with `SUDO_ASKPASS` set to
`/usr/local/sbin/motionmodule-askpass`. That script fetches it through
`motionmodule-update password`, which the rule also allows, and the helper
answers only processes inside the update's own unit. A second transient unit
deletes the file when the update ends. Runtime changes otherwise require
an explicit `motionmodule install REF`, `motionmodule activate NAME`, or
`motionmodule rollback`. Rollback returns to the earlier release of the same
branch when one is kept; switching branches is always `motionmodule install`.

### Default Mecanum modes

Fresh installs select Mecanum with teleop, Pi IMU support, and the four-turn
IMU autonomous routine. On upgrades, existing `robots/Mecanum` folders and the active project are
preserved; no missing file is added to an existing project. Use the explicit
Code-page sample action if you want the latest bundled example.
Select Autonomous, confirm the area is clear, Enable, then Start to run it;
installing or starting the service never starts motion.

## Module variants

Use `motionmodule install testing --variant mini` for four motors on two drivers,
or `--variant standard` for eight motors on four drivers. Both keep the same
sixteen servo outputs and Pi-connected MPU6500. A fresh checkout can use
`bash install.sh --version testing --variant mini`. The installed module choice
is kept in `~/.config/motionmodule/variant` and survives updates.

Changing module keeps the same active robot project and every file. Each update
saves a code snapshot under `~/MotionModule/backups`. Mini exposes only channels
1–4 from the existing map in memory, without rewriting it. Code requesting motors
5–8 may need changes on Mini; the files are preserved even if it cannot run. See the
[Mini build guide](../MotionModuleMini/README.md) for its parts and pinout.

The current `motionmodule install` command snapshots robot files before handing
control to the destination branch's bootstrap. This keeps code recoverable even
when deliberately installing a release older than this preservation policy;
older installers may still refresh bundled samples. The current installer keeps
the same active project and all existing project code in place.

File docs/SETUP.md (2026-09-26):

# Raspberry Pi setup and commissioning

## 1. Image the Pi

Use current Raspberry Pi OS in Raspberry Pi Imager. In its customization page:

- create a normal username and a strong password;
- enter the Wi-Fi the robot should normally use;
- set the correct Wi-Fi country; and
- enable SSH for installation and future administration.

The Wi-Fi saved here is the first preferred network. MotionModule can add or
replace preferred networks later from Debug.

## 2. Install MotionModule

Boot the Pi and connect to it once. Then run as the normal user, without putting
`sudo` before the command:

```bash
curl -fsSL https://raw.githubusercontent.com/AloeVeraZ/MotionModule/main/install.sh | bash
```

For multiple robots, give each a distinct hostname:

```bash
curl -fsSL https://raw.githubusercontent.com/AloeVeraZ/MotionModule/main/install.sh | \
  bash -s -- --hostname motionmodule-01
```

The installer creates versioned software, the persistent robot workspace,
system services, Nginx, I2C/GPIO access, mDNS, and Wi-Fi failover. It runs
MotionModule Doctor automatically, prints the pinout link last, and reboots.

## 3. Open the dashboard

After reboot, put the laptop on the same Wi-Fi and open:

```text
http://motionmodule.local
```

Use the Pi IP if `.local` discovery is blocked. If no saved Wi-Fi connects
within 30 seconds, join `MotionModule` with initial password `motionrobot` and
open `http://10.42.0.1`.

Debug shows all current IP addresses and lets you rename the hostname, scan and
join Wi-Fi, or start the robot hotspot for this boot. After a network switch,
join the same destination network on the laptop and reopen the hostname. The
next reboot always tries saved client Wi-Fi first.

## 4. Wire and inspect hardware

Read [PINOUT.md](PINOUT.md) and [the bill of materials](../BOM.md) before
applying motor or servo power.

- Motor battery positive goes only to the fused motor rail and H-bridges.
- PCA9685 VCC is Pi-side logic power; servo V+ comes from a separate fused
  5–6 V supply.
- Connect all signal grounds.
- Keep motor power off through boot and confirm the outputs stay still.
- Keep a physical motor-power cutoff reachable.

Open Debug. Its header and H-bridge labels are generic Driver 1A through 4B,
independent of the selected robot style. PCA9685 boards are checked through
I2C. USB devices appear with their IDs, Pi ports, drivers, and access state.
Basic H-bridge and servo outputs cannot identify attached hardware.

With all wheels raised, use the guarded Motor Bench Test at half power. Test
servos one channel at a time after selecting the correct voltage and behavior.

## 5. Connect the Pi IMU

The reference Mecanum setup keeps its motors, servo controller and MPU6500
on the Pi. The IMU uses the independent bus shown in **Debug → Wiring**:
VCC to physical pin 17, GND to 6 and AD0 to 20, SDA to 11 and SCL to 12.
Follow the [complete MPU6500 guide](PINOUT.md#optional-mpu6500-six-axis-imu),
including the board's I2C mode and pull-up notes.

The Pi installer adds this under `[all]` in `/boot/firmware/config.txt` and
reboots. If setting up without the installer, add it yourself and reboot:

```ini
dtoverlay=i2c-gpio,i2c_gpio_sda=17,i2c_gpio_scl=18
```

Use `i2cdetect -l` to confirm the independent adapter exists, then run
**Debug → Checks & logs**. The sample's `sensors.py` reads the MPU6500 on that
bus automatically. It does not use the servo bus or an Arduino for heading.
Without the IMU the robot still drives, with heading unavailable.

### Optional USB GPIO expansion

For additional sensors, an Arduino **GIGA R1 WiFi** may be connected to the
Pi by a USB-C data cable as extra GPIO inputs. This is an experimental extra
and may need troubleshooting on your hardware. The reference sample declares
no additional sensors. Uno and Mega boards cannot use the bundled GIGA firmware.

The existing USB discovery code recognizes the GIGA. Install its bridge
firmware from **Debug → Checks & logs → Install firmware**, or run:

```bash
motionmodule giga flash
motionmodule giga status
```

Flashing replaces the board's sketch, stops motors and restarts the GIGA.
The Pi uses the bundled firmware and `dfu-util`; no Arduino IDE is needed.
After flashing, declare only the extra inputs you actually wire, using
[the Python GPIO API](CODING.md#optional-usb-gpio-expansion). Board detection
does not identify attached sensors. The Pi sends your declarations on each
connection; a pin-list change does not require reflashing. GIGA GPIO takes
3.3 V maximum. The robot's MPU6500 stays connected directly to the Pi.

## 6. Create and deploy robot code

Open **Code → Deploy** and download the Mecanum sample. Unzip it and
rename the folder for the robot. The sample folder contains:

```text
MyRobot/
├── robot.py
├── hardware.py
├── sensors.py
├── autonomous.py
├── dashboard.py
└── any_other_python_files.py
```

Edit the local folder in any editor. `hardware.py` owns this robot's pins,
inversion, PWM, watchdog, and servo board list. `robot.py` defines
`create_drive(module)` and imports `sensors.py`, which reads the Pi-connected
MPU6500. See [CODING.md](CODING.md) for the APIs and examples.

Return to Code, choose the whole folder, review its files, accept the output
stop/restart confirmation, and press **Deploy and run**. The Pi validates it,
backs up an older same-named folder, makes the new copy active, restarts, and
automatically reconnects the page. A failed check does not replace the working
project.

## 7. Test the active project

Start with the speed limit low and the robot raised. Enable keyboard drive
deliberately:

- W/S: forward/backward
- A/D: strafe
- Q/E: rotate
- Space: stop

Releasing a key, disabling drive, leaving the page, or losing communication
sends or causes a stop. The 500 ms default hardware watchdog protects against a
lost browser command, but it does not replace the physical cutoff.

## 8. Use Doctor, logs, and terminal

Useful commands are explained inside Debug:

```bash
motionmodule doctor
motionmodule pinout
motionmodule status
motionmodule logs
motionmodule restart
motionmodule project list
motionmodule giga status
```

The web terminal is an unprivileged real Bash shell and is locked by default.
Create a temporary access code during an admin SSH session:

```bash
motionmodule terminal enable
```

Enter that code at the bottom of Code. It expires after 15 minutes by default,
is invalid after reboot, and its shell closes after five idle minutes. Revoke it
with `motionmodule terminal disable`. Do not enter reusable secrets because the
local robot dashboard uses HTTP.

## 9. Update MotionModule

A Pi with internet access checks GitHub by itself. Open **Debug -> Checks &
logs**; *MotionModule updates* is the first card.

1. Each branch gets a line. Green means this robot already runs the newest
   version of it, red means an update is waiting, and the card says which
   commit the Pi has against the one on GitHub.
2. A Pi installed from `testing` sees both lines: its own, and `main` with
   **Switch to the main line** for going back to stable. A Pi installed from
   `main` sees only `main`.
3. **Update now** asks once, then stops the motors and installs in the
   background. The output appears under the card. After a successful install,
   the whole Pi reboots automatically and the dashboard reconnects on its own
   after a minute or two; keep the robot powered until it does.
4. If `sudo` on the Pi asks for your password, a **Password required for
   update** popup asks for it first. It is the password of the Pi user you
   installed MotionModule as. A wrong one is refused before anything starts;
   the right one is used for this update only and deleted when it ends. A Pi
   whose `sudo` needs no password never shows the popup.

Robot folders, `hardware.py`, the active project, and Wi-Fi settings are kept,
the tests run before the new version is switched on, and a version that will
not start is rolled back. Checks repeat every 15 minutes; **Check now** asks
straight away. Nothing is ever installed without pressing the button.

## Troubleshooting

### The update card says the helper is missing

Updating from the dashboard needs `/usr/local/sbin/motionmodule-update`, which
only installs from this version onwards. Update once over SSH:

```bash
motionmodule install testing
```

The button works from then on.

### The update says its helper is too old to pass on a password

`sudo` on this Pi asks for a password, and the Pi was set up before the update
button could ask for one. Update once over SSH, where `sudo` asks in the
terminal:

```bash
motionmodule install testing
```

From then on the dashboard shows the password popup instead. Use SSH rather
than the Code-page terminal for this: that terminal belongs to the MotionModule
service, which restarts partway through the install.

### The update card cannot reach GitHub

The Pi is on Wi-Fi with no route to the internet, which is normal on its own
hotspot. Join a network with internet access, or update over SSH. The card
never guesses; it says so instead.

### The Pi is online but the website does not open

Use `http://`, not `https://`, and try the numeric IP. On the Pi:

```bash
sudo systemctl status nginx motionmodule.service --no-pager
curl http://127.0.0.1:8080/healthz
sudo nginx -t
```

### A deployment is rejected

The selected folder must contain a top-level `robot.py` and may contain only
`.py`, `.ino`, `.md`, and `.txt` files. A `hardware.py` is optional, but when present it
must hold literal data only. Read the exact Driver Station message: syntax and
hardware-map failures are rejected before anything is replaced.

### The service repeatedly restarts after a deployment

The static checks cannot prove that every imported third-party package exists
or that import-time student code succeeds. Open Debug's service log or run:

```bash
sudo journalctl -u motionmodule.service -n 100 --no-pager
```

Correct the local folder and deploy it again. Previous copies are retained in
`~/MotionModule/backups`.

### The Pi resets or the whole robot loses power at high motor output

Do not repeatedly reproduce a full-power shutdown. A software watchdog cannot
keep a Pi alive after its supply disappears. The motor commands are PWM duty
cycles, not measured amperes: 100% requests continuous drive, and neither the
H-bridges nor this code report battery voltage or motor current.

**Debug → Checks & logs → Run checks** and `motionmodule doctor` now read
`vcgencmd get_throttled` without moving anything. The Pi can report current
undervoltage and undervoltage recorded during this boot. These firmware flags
are not a battery gauge. They reset on reboot, and a fast supply cutoff can
leave no warning, so a clean reading does not establish that the power system
is adequate. Missing or unsupported diagnostics are reported as unavailable,
not as a good supply. See the [official flag definitions](https://www.raspberrypi.com/documentation/computers/os.html#get_throttled).

Inspect the actual battery, fuse markings, switch/connectors, driver ratings,
and the Pi's 12 V-to-5 V converter with actuator power disconnected. A driver
board's amp rating is not necessarily the main fuse rating. Do not bypass or
increase a fuse to hide the symptom. A conventional blown blade fuse stays
open; automatic recovery suggests another mechanism, such as converter
protection or a voltage dip, rather than proving the fuse blew.

Acceleration ramps can reduce startup transients but change acceleration and
do not protect against sustained overload. Power caps reduce available output.
Neither has been enabled automatically. Keeping full requested motor output
while guaranteeing Pi power requires an adequately sized, protected supply
system; software alone cannot create that current capacity. Hardware changes
must be reviewed by the owner and must not alter the locked pinout.

### The hotspot never appears

Wait at least 30 seconds. Any working saved Wi-Fi intentionally prevents the
fallback. Inspect `motionmodule-network.service` if necessary.

### GPIO or I2C says permission denied

Reboot after installation. Confirm the user belongs to `gpio` and `i2c` and
that `/dev/gpiochip0` and `/dev/i2c-1` exist.

### Optional GIGA expansion is not found, or readings stay empty

- `motionmodule giga status` should list it. If not, try another cable: many
  USB-C cables only carry power.
- *Permission denied* opening `/dev/ttyACM0`: the installer adds the user to
  `dialout` and `plugdev`. Reboot once after installing.
- The Driver Station says it runs the original bridge sketch, or a different
  firmware version: install the firmware again from Debug.
- A flash that says the GIGA did not enter its bootloader: press the GIGA's
  RESET button twice quickly, so its green light pulses, and install again.

### A motor moves briefly and stops

The watchdog is working. Robot logic that maintains nonzero output must refresh
commands faster than the configured timeout.

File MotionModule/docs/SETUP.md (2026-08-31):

# Raspberry Pi installation and commissioning

## 1. Prepare Raspberry Pi OS

Use Raspberry Pi Imager to install a current Raspberry Pi OS release on a
Raspberry Pi 4, the tested hardware target. The
64-bit Lite image is sufficient; Desktop also works. In Imager customization:

- create a normal username and strong password;
- enable SSH;
- configure a 2.4/5 GHz Wi-Fi network or plan to use Ethernet;
- give every classroom Pi a unique hostname if possible;
- set the correct locale and timezone.

Before motor power is ever attached, add the input pull-downs described in
[PINOUT.md](PINOUT.md). Software cannot control a GPIO during the Pi's early
boot or while it has no power.

Ethernet is the most dependable first-install connection. Normal Wi-Fi is the
most convenient everyday editing connection. Bluetooth is not used because it
does not provide a consistent SSH/deployment path, and USB gadget networking is
not the default because support and cabling differ across Pi models.

## 2. Install MotionModule

SSH into the Pi, then run the installer as that normal user:

```bash
curl -fsSL https://raw.githubusercontent.com/AloeVeraZ/MotionModule/main/install.sh | \
  bash -s -- --hostname motionmodule-01
```

The script requests sudo only for APT, GPIO/I2C groups, SSH/mDNS, hostname, and
the systemd service. It performs these operations in order:

1. installs `lgpio`, I2C, Python, NetworkManager, Nginx, SSH, and mDNS packages;
2. enables I2C and adds the installing user to the `gpio`/`i2c` groups;
3. copies the requested code into a new timestamped release directory;
4. creates an isolated Python environment and runs the complete unit test suite;
5. copies each bundled robot-project folder only when it does not already exist;
6. points `~/MotionModule/active` at the selected project and creates the persistent config;
7. switches the `current` symlink only after validation succeeds;
8. records the active Raspberry Pi Imager Wi-Fi as the preferred network;
9. enables the dashboard/runtime, port-80 proxy, and 30-second Wi-Fi failover service;
10. runs the non-moving `motionmodule doctor` check and prints its results;
11. links to the GitHub pinout as its final message, then reboots automatically.

The SSH connection closes when the automatic reboot begins. Wait for the Pi to
come back online before reconnecting. For a provisioning workflow that still
has additional work to do, skip only the reboot with:

```bash
curl -fsSL https://raw.githubusercontent.com/AloeVeraZ/MotionModule/main/install.sh | \
  bash -s -- --no-reboot
```

## 3. Non-moving checks

The installer already ran `doctor` before reboot. After wiring against
[PINOUT.md](PINOUT.md), reconnect and run the checks again before applying motor
power:

```bash
motionmodule status
motionmodule doctor
motionmodule pinout
```

`doctor` can confirm the config, GPIO access, SPI conflicts, service, and every
configured PCA9685 I2C address. The H-bridge boards have no return data line, so
their presence cannot be detected without moving a motor or adding current/
encoder feedback hardware.

If the PCA9685 is absent—as expected during early development—`doctor` reports a
warning and motor service remains usable. Install the board later and rerun the
same check.

## 4. Raised-wheel motor commissioning

Read [PINOUT.md](PINOUT.md), raise the chassis, and keep the cutoff nearby.
Normal robot code must be stopped so two processes cannot claim GPIO:

```bash
motionmodule stop
motionmodule test-motor 1
motionmodule test-motor 2
```

The diagnostic requires typing `RAISED`, limits power to 25% and duration to two
seconds, and stops through a `finally`/context cleanup path. Test all eight
channels. Missing motor/driver wiring produces no software discovery error; the
physical channel simply will not move.

For a wheel that runs opposite its semantic direction, edit only its
`inverted = true/false` value:

```bash
nano ~/.config/motionmodule/config.toml
motionmodule start
```

## 5. Servo commissioning

Set the external servo regulator with a multimeter before attaching a servo.
Start with mechanical linkage disconnected and a centered command:

```bash
motionmodule stop
motionmodule test-servo 0 --board 0 --angle 90
```

If the board is not found, run `i2cdetect -y 1`. The default board should appear
at `40`. Check SDA/SCL orientation, 3.3 V logic VCC, common ground, and address
pads. A servo may still fail to move with a detected board if its separate V+
rail is absent.

## 6. Student editing

Install VS Code and the Microsoft Remote - SSH extension on the laptop. Connect
to `YOUR_USER@motionmodule-01.local`, open `~/MotionModule`, and edit the
active robot folder. The included default is `Mecanum`. Restart and watch logs
from the VS Code terminal:

```bash
motionmodule restart
motionmodule logs
```

To add another robot, create `~/MotionModule/Swerve/robot.py` (or another
project-named folder), then select it:

```bash
motionmodule project list
motionmodule project Swerve
```

The dashboard's Code page shows the active project. Reinstalling or updating
the runtime does not overwrite any existing robot project folder.

The complete dashboard is `http://motionmodule-01.local`; the Pi's current IP
address also works directly without adding a port. A network
disconnect stops motor output after 500 ms even if the browser stop request
never reaches the Pi. Open **Network** for the active network, IP addresses,
nearby Wi-Fi scan, and hotspot controls. Every network change stops the motors.
The **Hardware** page has the pin diagram and guarded motor/servo bench tests;
**Doctor** has non-moving checks and service logs.

## 7. Wi-Fi and automatic standalone hotspot

On every boot, NetworkManager first tries the Wi-Fi profiles already saved on
the Pi. The installer records whichever client Wi-Fi is active—normally the one
entered in Raspberry Pi Imager—as MotionModule's preferred profile. If the Pi
does not have a working client connection within 30 seconds, it creates:

- SSID: `MotionModule`
- password: `motionrobot` on a fresh install
- robot address: `http://10.42.0.1`

Change the hotspot name/password from the browser Settings screen before using
it in a shared classroom. Settings can also scan and join open, WPA personal,
or PEAP/MSCHAPv2 enterprise networks. Enterprise setup requires the username,
password, and authentication server's full DNS domain so the Pi can validate
the server certificate. Use `nmtui` through SSH for other school configurations.

Press **Switch to robot hotspot** to leave the current LAN and start the access
point immediately. That manual choice applies to the current boot only. At the
next boot, the Pi again tries preferred Wi-Fi for 30 seconds first. The matching
terminal commands remain available:

```bash
motionmodule hotspot on MotionModule-01 choose-a-password
motionmodule hotspot off
motionmodule hotspot status
```

`hotspot off` reconnects the saved preferred profile. Ethernet can remain
connected while the Wi-Fi adapter serves the hotspot.

### Finding the address after changing Wi-Fi

The Network page shows every current IPv4 address and the stable mDNS name
`http://HOSTNAME.local`. When the Pi switches away from its hotspot, the
old browser loses contact before it can learn the new DHCP address; that is a
normal one-radio handoff. Join the destination Wi-Fi on the laptop and open the
`.local` name. If `.local` is unavailable on that laptop/network, find the Pi in
the router's client list or SSH in and run `hostname -I`.

## Troubleshooting

### Service repeatedly restarts

```bash
motionmodule status
sudo journalctl -u motionmodule.service -n 100 --no-pager
```

A syntax error in student `robot.py`, a GPIO already claimed by another process,
or active SPI on expansion pins are common causes.

### The Pi is online but the dashboard does not open

Use `http://` rather than `https://`, then check both services:

```bash
sudo systemctl status nginx motionmodule.service --no-pager
curl http://127.0.0.1:8080/healthz
sudo nginx -t
```

Port 8080 is the private dashboard process; Nginx exposes it as normal port 80.

### `.local` address does not resolve

Use the IP shown by `hostname -I`, your router, or `10.42.0.1` in hotspot mode.
Confirm `systemctl status avahi-daemon` on the Pi.

### The hotspot never appears

Wait at least 30 seconds after boot, then check Ethernet and the saved Wi-Fi—any
working client connection intentionally prevents fallback. Inspect the monitor
with `sudo systemctl status motionmodule-network.service` and
`sudo journalctl -u motionmodule-network.service -n 100 --no-pager`.

### Permission denied for GPIO/I2C

Reboot after installation. Confirm `groups` includes `gpio` and `i2c`, and that
`/dev/gpiochip0` and `/dev/i2c-1` exist.

### The robot moves briefly and stops

The 500 ms watchdog is working. Long-running code must refresh motor commands or
call `module.feed_watchdog()` faster than the configured timeout. Do not disable
the watchdog to hide a blocked control loop.

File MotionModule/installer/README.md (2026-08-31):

# Installer behavior

Run the repository entry point, not this file directly:

```bash
bash install.sh --hostname motionmodule-01
```

Or after the repository is published:

```bash
curl -fsSL https://raw.githubusercontent.com/AloeVeraZ/MotionModule/main/install.sh | \
  bash -s -- --version main --hostname motionmodule-01
```

Options:

| Option | Meaning |
| --- | --- |
| `--version REF` | Explicit Git branch, tag, or fetchable commit to install |
| `--hostname NAME` | Set the Pi's mDNS hostname |
| `--robot PROJECT` | Select a bundled robot-project folder; defaults to `Mecanum` |
| `--no-hostname` | Preserve the current hostname |
| `--no-start` | Install and enable the service without starting it |
| `--no-reboot` | Skip the default automatic reboot |

The bootstrap downloads the requested ref to a temporary directory. The main
installer installs system dependencies, copies that source into a new release,
creates a per-release virtual environment, runs unit tests, and marks the
release complete. Only then is `current` switched. An error before activation
leaves the previous service target unchanged.

The central source directory may contain multiple direct child folders with
`robot.py`. Each is copied once into `~/MotionModule`, while an `active` symlink
selects the project loaded by the service. Existing robot folders are never
overwritten. After installation, use `motionmodule project list` and
`motionmodule project PROJECT_NAME` to inspect or switch them.

It also installs the root-owned constrained network helper and
`motionmodule-network.service`. The helper records the active Imager-created
Wi-Fi during installation. At boot, the service allows saved client Wi-Fi 30
seconds to connect before starting the protected `MotionModule` hotspot. The
versioned dashboard can invoke only the helper's fixed status, scan, connect,
preferred-network, and hotspot operations through a dedicated sudoers rule.

Nginx is installed as a port-80 reverse proxy to the dashboard on
`127.0.0.1:8080`. This makes both `http://HOSTNAME.local` and a bare Pi IP work
without asking students to remember a port number.
The stable dashboard launcher falls back to the original `motion_module.runner`
for pre-0.2.0 releases, preserving explicit rollback after the service unit has
been upgraded.

After activation, the installer automatically runs the non-moving
`motionmodule doctor` check, prints its results, and reboots so the new GPIO/I2C
group membership and boot configuration take effect. Its final message links
directly to the GitHub pinout. Use `--no-reboot` only when another provisioning
step must run before rebooting.

The first install defaults to hostname `motionmodule`. Later installs preserve
the active hostname unless `--hostname` is explicitly supplied.

No automatic update service or timer is installed. Use
`motionmodule install REF`, inspect `motionmodule versions`, and use
`motionmodule rollback` or `motionmodule activate NAME` explicitly.

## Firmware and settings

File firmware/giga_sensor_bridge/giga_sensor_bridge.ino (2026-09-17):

/* MotionModule sensor bridge for the Arduino GIGA R1 WiFi.

   The GIGA is the robot's sensor board, and nothing more. It reads the pins
   and I2C registers the Raspberry Pi asks for and sends the numbers straight
   up the USB cable. It does no maths and knows nothing about any particular
   sensor: the Pi decides what to read, when to read it, and what the readings
   mean. One copy of this firmware therefore serves every robot, and changing
   sensors never means reflashing.

   No Arduino IDE is needed. With the GIGA plugged into the Pi, run

       motionmodule giga flash

   or press Install firmware under Debug. The Pi flashes the prebuilt copy of
   this sketch, firmware/giga_sensor_bridge.bin. The IDE still works: install
   "Arduino Mbed OS Giga Boards", pick Arduino Giga R1, and upload.

   Every message is one line. From the Pi:

     MM3 CONFIG <id> <ms> <pins or -> <streams or ->
         What to read, and how often. Pins are A0:A,D22:U; streams are I2C
         reads as ADDRESS:REGISTER:LENGTH in hex, such as 28:1A:6,6A:22:12.
         MM3 CONFIG 7 20 A0:A,D22:U 6A:22:12
     MM3 I2C <seq> <addr> R <reg> <len>      one read, answered once
     MM3 I2C <seq> <addr> W <reg> <hex>      one write, answered once
     MM3 SCAN <seq>                          which I2C addresses answer
     MM3 HELLO                               firmware version and limits
     MM1 CONFIG <pins>                       the original pins-only protocol

   Pin modes: A analog (0-4095), D digital, U digital with pull-up, N with
   pull-down. The GIGA's pins take 3.3 V at most.

   Back to the Pi: JSON lines tagged "protocol":"motionmodule-sensor-v3". A
   reading line carries the board's own millisecond clock, so the Pi can work
   out exactly how far apart two readings were taken.
*/

#include <Wire.h>
#include <stdarg.h>
#include <stdio.h>
#include <stdlib.h>
#include <string.h>

const char BRIDGE_VERSION[] = "3.0.0";
const char BRIDGE_BOARD[] = "arduino_giga_r1_wifi";
const char PROTOCOL[] = "motionmodule-sensor-v3";

constexpr int MAX_INPUTS = 20;
constexpr int MAX_STREAMS = 6;
constexpr int MAX_STREAM_BYTES = 32;
constexpr int MAX_WRITE_BYTES = 16;
constexpr unsigned long DEFAULT_INTERVAL_MS = 20;         // 50 readings a second
constexpr unsigned long MINIMUM_INTERVAL_MS = 5;
constexpr unsigned long MAXIMUM_INTERVAL_MS = 1000;
constexpr unsigned long LEGACY_INTERVAL_MS = 100;         // the original sketch's pace
constexpr unsigned long HELLO_INTERVAL_MS = 1000;
constexpr unsigned long BUS_CLOCK_HZ = 400000;
constexpr uint8_t FIRST_I2C_ADDRESS = 0x08;
constexpr uint8_t LAST_I2C_ADDRESS = 0x77;

// Types come before any function: the Arduino build adds a declaration of
// every function above the first one, and those name these types.

struct OutputLine {
  char text[1600];
  size_t length;
  bool overflow;
};

OutputLine output;

struct InputPin {
  char label[4];  // "A0" through "D75"
  int number;
  char mode;
};

InputPin inputs[MAX_INPUTS];
int inputCount = 0;

// One I2C read the Pi wants repeated with every reading.
struct I2cStream {
  uint8_t address;
  uint8_t reg;
  uint8_t length;
  uint8_t data[MAX_STREAM_BYTES];
  bool ok;
};

I2cStream streams[MAX_STREAMS];
int streamCount = 0;

// ------------------------------------------------------------------ output

void lineStart(OutputLine &line) {
  line.length = 0;
  line.overflow = false;
  line.text[0] = '\0';
}

void lineAdd(OutputLine &line, const char *format, ...) {
  if (line.overflow) return;
  size_t room = sizeof(line.text) - line.length;
  va_list arguments;
  va_start(arguments, format);
  int written = vsnprintf(line.text + line.length, room, format, arguments);
  va_end(arguments);
  if (written < 0 || (size_t)written >= room) {
    line.overflow = true;
    return;
  }
  line.length += (size_t)written;
}

void lineAddHex(OutputLine &line, const uint8_t *data, size_t length) {
  static const char digits[] = "0123456789abcdef";
  if (line.overflow) return;
  if (line.length + length * 2 + 1 >= sizeof(line.text)) {
    line.overflow = true;
    return;
  }
  for (size_t index = 0; index < length; index++) {
    line.text[line.length++] = digits[data[index] >> 4];
    line.text[line.length++] = digits[data[index] & 0x0F];
  }
  line.text[line.length] = '\0';
}

// One write per message: printing piece by piece sends a USB packet per piece.
void lineSend(OutputLine &line) {
  lineAdd(line, "\n");
  if (line.overflow) return;  // never send half a message
  Serial.write((const uint8_t *)line.text, line.length);
}

// -------------------------------------------------------------------- pins

int resolvePin(const char *label, char mode) {
  bool analog = label[0] == 'A';
  if (!analog && label[0] != 'D') return -1;
  if ((mode == 'A') != analog) return -1;
  if (label[1] < '0' || label[1] > '9') return -1;
  if (label[2] != '\0' && (label[2] < '0' || label[2] > '9')) return -1;
  int number = atoi(label + 1);
  if (analog) {
    static const int analogPins[] = {A0, A1, A2, A3, A4, A5, A6, A7};
    return number < 8 ? analogPins[number] : -1;
  }
  return number <= 75 ? number : -1;
}

// Reads "A0:A,D22:U" into pins. Returns how many, or -1 if any entry is wrong.
int parsePins(const char *text, InputPin *pins) {
  if (strcmp(text, "-") == 0) return 0;
  int count = 0;
  const char *cursor = text;
  while (*cursor != '\0') {
    if (count == MAX_INPUTS) return -1;
    const char *comma = strchr(cursor, ',');
    size_t length = comma != nullptr ? (size_t)(comma - cursor) : strlen(cursor);
    if (length < 4 || length > 5 || cursor[length - 2] != ':') return -1;
    InputPin pin;
    memcpy(pin.label, cursor, length - 2);
    pin.label[length - 2] = '\0';
    pin.mode = cursor[length - 1];
    if (pin.mode != 'A' && pin.mode != 'D' && pin.mode != 'U' && pin.mode != 'N') return -1;
    pin.number = resolvePin(pin.label, pin.mode);
    if (pin.number < 0) return -1;
    pins[count++] = pin;
    if (comma == nullptr) break;
    cursor = comma + 1;
  }
  return count;
}

void applyPins(const InputPin *pins, int count) {
  for (int index = 0; index < count; index++) {
    inputs[index] = pins[index];
    if (pins[index].mode == 'U') pinMode(pins[index].number, INPUT_PULLUP);
    else if (pins[index].mode == 'N') pinMode(pins[index].number, INPUT_PULLDOWN);
    else if (pins[index].mode == 'D') pinMode(pins[index].number, INPUT);
  }
  inputCount = count;
}

int readPin(const InputPin &pin) {
  if (pin.mode == 'A') return analogRead(pin.number);
  return digitalRead(pin.number) == HIGH ? 1 : 0;
}

// --------------------------------------------------------------------- I2C

bool busRead(uint8_t address, uint8_t reg, uint8_t *data, size_t length) {
  Wire.beginTransmission(address);
  Wire.write(reg);
  if (Wire.endTransmission(false) != 0) return false;
  size_t received = Wire.requestFrom(address, length);
  if (received != length) {
    while (Wire.available() > 0) Wire.read();
    return false;
  }
  for (size_t index = 0; index < length; index++) data[index] = (uint8_t)Wire.read();
  return true;
}

bool busWrite(uint8_t address, uint8_t reg, const uint8_t *data, size_t length) {
  Wire.beginTransmission(address);
  Wire.write(reg);
  for (size_t index = 0; index < length; index++) Wire.write(data[index]);
  return Wire.endTransmission() == 0;
}

bool busAnswers(uint8_t address) {
  Wire.beginTransmission(address);
  return Wire.endTransmission() == 0;
}

int hexValue(char character) {
  if (character >= '0' && character <= '9') return character - '0';
  if (character >= 'a' && character <= 'f') return character - 'a' + 10;
  if (character >= 'A' && character <= 'F') return character - 'A' + 10;
  return -1;
}

// Reads "1a2b" into bytes. Returns how many, or -1 if it is not full bytes.
int parseHex(const char *text, uint8_t *data, int limit) {
  size_t length = strlen(text);
  if (length == 0 || length % 2 != 0 || (int)(length / 2) > limit) return -1;
  for (size_t index = 0; index < length; index += 2) {
    int high = hexValue(text[index]);
    int low = hexValue(text[index + 1]);
    if (high < 0 || low < 0) return -1;
    data[index / 2] = (uint8_t)((high << 4) | low);
  }
  return (int)(length / 2);
}

// Reads "28:1A:6,6A:22:12" into streams. Returns how many, or -1.
int parseStreams(const char *text, I2cStream *into) {
  if (strcmp(text, "-") == 0) return 0;
  int count = 0;
  const char *cursor = text;
  while (*cursor != '\0') {
    if (count == MAX_STREAMS) return -1;
    const char *comma = strchr(cursor, ',');
    size_t length = comma != nullptr ? (size_t)(comma - cursor) : strlen(cursor);
    char item[16];
    if (length == 0 || length >= sizeof(item)) return -1;
    memcpy(item, cursor, length);
    item[length] = '\0';
    char *registerText = strchr(item, ':');
    if (registerText == nullptr) return -1;
    *registerText++ = '\0';
    char *lengthText = strchr(registerText, ':');
    if (lengthText == nullptr) return -1;
    *lengthText++ = '\0';
    char *end = nullptr;
    long address = strtol(item, &end, 16);
    if (end == item || *end != '\0' || address < FIRST_I2C_ADDRESS || address > LAST_I2C_ADDRESS) return -1;
    long reg = strtol(registerText, &end, 16);
    if (end == registerText || *end != '\0' || reg < 0 || reg > 0xFF) return -1;
    long bytes = strtol(lengthText, &end, 10);
    if (end == lengthText || *end != '\0' || bytes < 1 || bytes > MAX_STREAM_BYTES) return -1;
    I2cStream stream;
    memset(&stream, 0, sizeof(stream));
    stream.address = (uint8_t)address;
    stream.reg = (uint8_t)reg;
    stream.length = (uint8_t)bytes;
    into[count++] = stream;
    if (comma == nullptr) break;
    cursor = comma + 1;
  }
  return count;
}

// ---------------------------------------------------------------- messages

char activeConfig[320] = "";
long configId = -1;
int protocolMode = 0;  // 0 until the Pi configures it, 1 original protocol, 3 current
unsigned long interval = DEFAULT_INTERVAL_MS;
unsigned long lastReading = 0;
unsigned long lastHello = 0;
unsigned long sequence = 0;

void eventStart(const char *event) {
  lineStart(output);
  lineAdd(output, "{\"protocol\":\"%s\",\"event\":\"%s\",\"firmware\":\"%s\"", PROTOCOL, event, BRIDGE_VERSION);
}

void sendHello() {
  eventStart("hello");
  lineAdd(output, ",\"board\":\"%s\",\"streams\":%d,\"stream_bytes\":%d,\"pins\":%d}",
          BRIDGE_BOARD, MAX_STREAMS, MAX_STREAM_BYTES, MAX_INPUTS);
  lineSend(output);
}

void sendConfigured() {
  eventStart("configured");
  lineAdd(output, ",\"config\":%ld,\"pins\":%d,\"streams\":%d,\"interval\":%lu}",
          configId, inputCount, streamCount, interval);
  lineSend(output);
}

void sendError(const char *message) {
  eventStart("error");
  lineAdd(output, ",\"message\":\"%s\"}", message);
  lineSend(output);
}

void sendReadings(unsigned long now) {
  lineStart(output);
  lineAdd(output, "{\"protocol\":\"%s\",\"firmware\":\"%s\",\"config\":%ld,\"seq\":%lu,\"ms\":%lu,\"values\":{",
          PROTOCOL, BRIDGE_VERSION, configId, ++sequence, now);
  for (int index = 0; index < inputCount; index++) {
    lineAdd(output, "%s\"%s\":%d", index ? "," : "", inputs[index].label, readPin(inputs[index]));
  }
  lineAdd(output, "},\"i2c\":{");
  for (int index = 0; index < streamCount; index++) {
    I2cStream &stream = streams[index];
    lineAdd(output, "%s\"%02x:%02x\":", index ? "," : "", (unsigned)stream.address, (unsigned)stream.reg);
    if (stream.ok) {
      lineAdd(output, "\"");
      lineAddHex(output, stream.data, stream.length);
      lineAdd(output, "\"");
    } else {
      lineAdd(output, "null");  // the sensor did not answer this time
    }
  }
  lineAdd(output, "}}");
  lineSend(output);
}

void sendLegacyReadings() {
  lineStart(output);
  lineAdd(output, "{\"protocol\":\"motionmodule-sensor-v1\",\"board\":\"%s\",\"firmware\":\"%s\",\"values\":{",
          BRIDGE_BOARD, BRIDGE_VERSION);
  for (int index = 0; index < inputCount; index++) {
    lineAdd(output, "%s\"%s\":%d", index ? "," : "", inputs[index].label, readPin(inputs[index]));
  }
  lineAdd(output, "}}");
  lineSend(output);
}

void handleConfig(const char *arguments) {
  // The same request again, as when the Pi reconnects: nothing to change.
  if (protocolMode == 3 && strcmp(arguments, activeConfig) == 0) return sendConfigured();
  char copy[sizeof(activeConfig)];
  if (strlen(arguments) >= sizeof(copy)) return sendError("config is too long");
  strcpy(copy, arguments);
  char *idText = strtok(copy, " ");
  char *intervalText = strtok(nullptr, " ");
  char *pinText = strtok(nullptr, " ");
  char *streamText = strtok(nullptr, " ");
  if (idText == nullptr || intervalText == nullptr || pinText == nullptr || streamText == nullptr ||
      strtok(nullptr, " ") != nullptr) {
    return sendError("expected MM3 CONFIG <id> <ms> <pins> <streams>");
  }
  char *end = nullptr;
  long id = strtol(idText, &end, 10);
  if (*end != '\0' || id < 0) return sendError("config id must be a whole number");
  long milliseconds = strtol(intervalText, &end, 10);
  if (*end != '\0' || milliseconds < (long)MINIMUM_INTERVAL_MS || milliseconds > (long)MAXIMUM_INTERVAL_MS) {
    return sendError("reading interval is out of range");
  }
  InputPin pins[MAX_INPUTS];
  int pinCount = parsePins(pinText, pins);
  if (pinCount < 0) return sendError("pin list not understood");
  I2cStream parsed[MAX_STREAMS];
  int parsedCount = parseStreams(streamText, parsed);
  if (parsedCount < 0) return sendError("I2C stream list not understood");

  applyPins(pins, pinCount);
  for (int index = 0; index < parsedCount; index++) streams[index] = parsed[index];
  streamCount = parsedCount;
  interval = (unsigned long)milliseconds;
  configId = id;
  strcpy(activeConfig, arguments);
  protocolMode = 3;
  lastReading = millis();
  sendConfigured();
}

void handleLegacyConfig(const char *declaration) {
  InputPin pins[MAX_INPUTS];
  int count = parsePins(declaration, pins);
  applyPins(pins, count < 0 ? 0 : count);
  streamCount = 0;
  activeConfig[0] = '\0';
  configId = -1;
  protocolMode = 1;
  lineStart(output);
  lineAdd(output, "{\"protocol\":\"motionmodule-sensor-v1\",\"event\":\"configured\",\"firmware\":\"%s\"}",
          BRIDGE_VERSION);
  lineSend(output);
}

// One read or write the Pi asked for, answered with the same seq it sent.
void handleI2c(char *arguments) {
  char *seqText = strtok(arguments, " ");
  char *addressText = strtok(nullptr, " ");
  char *directionText = strtok(nullptr, " ");
  char *registerText = strtok(nullptr, " ");
  char *valueText = strtok(nullptr, " ");
  if (seqText == nullptr || addressText == nullptr || directionText == nullptr ||
      registerText == nullptr || valueText == nullptr || strtok(nullptr, " ") != nullptr) {
    return sendError("expected MM3 I2C <seq> <addr> R|W <reg> <len or hex>");
  }
  char *end = nullptr;
  long seq = strtol(seqText, &end, 10);
  if (*end != '\0' || seq < 0) return sendError("I2C seq must be a whole number");
  long address = strtol(addressText, &end, 16);
  if (*end != '\0' || address < FIRST_I2C_ADDRESS || address > LAST_I2C_ADDRESS) {
    return sendError("I2C address is out of range");
  }
  long reg = strtol(registerText, &end, 16);
  if (*end != '\0' || reg < 0 || reg > 0xFF) return sendError("I2C register is out of range");

  uint8_t data[MAX_STREAM_BYTES];
  bool ok = false;
  int length = 0;
  if (directionText[0] == 'R' && directionText[1] == '\0') {
    length = (int)strtol(valueText, &end, 10);
    if (*end != '\0' || length < 1 || length > MAX_STREAM_BYTES) return sendError("I2C read length is out of range");
    ok = busRead((uint8_t)address, (uint8_t)reg, data, (size_t)length);
  } else if (directionText[0] == 'W' && directionText[1] == '\0') {
    length = parseHex(valueText, data, MAX_WRITE_BYTES);
    if (length < 0) return sendError("I2C write needs whole hex bytes");
    ok = busWrite((uint8_t)address, (uint8_t)reg, data, (size_t)length);
    length = 0;
  } else {
    return sendError("I2C direction must be R or W");
  }

  eventStart("i2c");
  lineAdd(output, ",\"seq\":%ld,\"addr\":%u,\"reg\":%u,\"ok\":%d", seq, (unsigned)address, (unsigned)reg, ok ? 1 : 0);
  if (ok && length > 0) {
    lineAdd(output, ",\"data\":\"");
    lineAddHex(output, data, (size_t)length);
    lineAdd(output, "\"");
  }
  lineAdd(output, "}");
  lineSend(output);
}

void handleScan(const char *arguments) {
  char *end = nullptr;
  long seq = strtol(arguments, &end, 10);
  if (*end != '\0' || seq < 0) return sendError("expected MM3 SCAN <seq>");
  eventStart("scan");
  lineAdd(output, ",\"seq\":%ld,\"found\":[", seq);
  int found = 0;
  for (uint8_t address = FIRST_I2C_ADDRESS; address <= LAST_I2C_ADDRESS; address++) {
    if (!busAnswers(address)) continue;
    lineAdd(output, "%s%u", found++ ? "," : "", (unsigned)address);
  }
  lineAdd(output, "]}");
  lineSend(output);
}

void handleLine(char *text) {
  size_t length = strlen(text);
  while (length > 0 && (text[length - 1] == ' ' || text[length - 1] == '\t')) text[--length] = '\0';
  while (*text == ' ' || *text == '\t') text++;
  if (strncmp(text, "MM3 CONFIG ", 11) == 0) handleConfig(text + 11);
  else if (strncmp(text, "MM3 I2C ", 8) == 0) handleI2c(text + 8);
  else if (strncmp(text, "MM3 SCAN ", 9) == 0) handleScan(text + 9);
  else if (strcmp(text, "MM3 HELLO") == 0) sendHello();
  else if (strncmp(text, "MM1 CONFIG ", 11) == 0) handleLegacyConfig(text + 11);
}

char command[384];
size_t commandLength = 0;
bool commandTooLong = false;

void readCommands() {
  for (int budget = 1024; budget > 0 && Serial.available() > 0; budget--) {
    int received = Serial.read();
    if (received < 0) break;
    if (received == '\r') continue;
    if (received == '\n') {
      command[commandLength] = '\0';
      if (!commandTooLong) handleLine(command);
      commandLength = 0;
      commandTooLong = false;
    } else if (commandLength + 1 < sizeof(command)) {
      command[commandLength++] = (char)received;
    } else {
      commandTooLong = true;
    }
  }
}

// -------------------------------------------------------------- status LED
// Blue blink: waiting for the Pi. Green blip: sending readings. Magenta
// double blink: an I2C sensor the Pi asked for is not answering; check its
// wiring. (A red 4-fast-4-slow pattern is the board's own crash signal.)

void showStatus(unsigned long now) {
  static unsigned long lastShown = 0;
  if (now - lastShown < 50) return;
  lastShown = now;
  unsigned long phase = now % 2000;
  bool red = false;
  bool green = false;
  bool blue = false;
  if (protocolMode == 0) {
    blue = phase < 100;
  } else {
    bool silent = false;
    for (int index = 0; index < streamCount; index++) {
      if (!streams[index].ok) silent = true;
    }
    if (silent) red = blue = phase < 150 || (phase >= 300 && phase < 450);
    else green = phase < 100;
  }
  // The GIGA's RGB LED lights when its pin is LOW.
  digitalWrite(LEDR, red ? LOW : HIGH);
  digitalWrite(LEDG, green ? LOW : HIGH);
  digitalWrite(LEDB, blue ? LOW : HIGH);
}

// ------------------------------------------------------------------- main

void setup() {
  Serial.begin(115200);
  analogReadResolution(12);
  Wire.begin();
  Wire.setClock(BUS_CLOCK_HZ);
  pinMode(LEDR, OUTPUT);
  pinMode(LEDG, OUTPUT);
  pinMode(LEDB, OUTPUT);
}

void loop() {
  unsigned long now = millis();
  readCommands();
  if (protocolMode == 3 && now - lastReading >= interval) {
    lastReading = now;
    for (int index = 0; index < streamCount; index++) {
      I2cStream &stream = streams[index];
      stream.ok = busRead(stream.address, stream.reg, stream.data, stream.length);
    }
    sendReadings(millis());  // the clock the Pi measures its intervals with
  } else if (protocolMode == 1 && now - lastReading >= LEGACY_INTERVAL_MS) {
    lastReading = now;
    sendLegacyReadings();
  } else if (protocolMode == 0 && now - lastHello >= HELLO_INTERVAL_MS) {
    lastHello = now;
    sendHello();
  }
  showStatus(now);
}

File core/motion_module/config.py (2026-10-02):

"""Typed configuration, friendly names, and pin-safety validation.

Everything MotionModule knows about a robot's wiring comes from one
``hardware.py`` file. The packaged default lives next to this module; a robot
project may ship its own copy to rename outputs or change pins.
"""

from __future__ import annotations

import ast
import os
import re
import tomllib
from dataclasses import dataclass, replace
from pathlib import Path
from pprint import pformat

from .errors import ConfigurationError


DEFAULT_HARDWARE_PATH = Path(__file__).with_name("hardware.py")
MINI_HARDWARE_PATH = Path(__file__).with_name("hardware_mini.py")
RESERVED_ID_GPIOS = {0, 1}
I2C_GPIOS = {2, 3}
VALID_BCM_GPIOS = set(range(28))
PROJECT_CONFIG_NAME = "hardware.py"
NAME_PATTERN = re.compile(r"[A-Za-z][A-Za-z0-9_]{0,31}")
SERVO_CHANNELS_PER_BOARD = 16


@dataclass(frozen=True)
class MotorConfig:
    channel: int
    name: str
    forward_gpio: int
    reverse_gpio: int
    inverted: bool = False


@dataclass(frozen=True)
class ServoSlot:
    """One named PCA9685 output: ``claw`` instead of ``board 0, channel 3``."""

    name: str
    board: int
    channel: int


@dataclass(frozen=True)
class ServoConfig:
    enabled: bool
    i2c_bus: int
    frequency_hz: int
    addresses: tuple[int, ...]
    minimum_pulse_us: int
    maximum_pulse_us: int
    channels: tuple[ServoSlot, ...] = ()
    # BCM pin wired to the board's OE pad, or None when OE is left alone.
    # OE is active low: driving it high cuts all 16 outputs in hardware,
    # whatever the PCA9685's own registers happen to hold.
    output_enable_gpio: int | None = None


@dataclass(frozen=True)
class ModuleConfig:
    pwm_hz: int
    deadtime_ms: int
    watchdog_ms: int
    motors: tuple[MotorConfig, ...]
    servos: ServoConfig
    variant: str = "standard"

    @property
    def motor_capacity(self) -> int:
        return 4 if self.variant == "mini" else 8

    def motor(self, channel: int) -> MotorConfig:
        try:
            return next(item for item in self.motors if item.channel == channel)
        except StopIteration as error:
            raise ConfigurationError(f"Motor channel {channel} is not configured") from error

    def motor_channel(self, reference: int | str) -> int:
        """Accept either a channel number or a name from ``hardware.py``."""

        if isinstance(reference, str):
            wanted = reference.strip().casefold()
            for item in self.motors:
                if item.name.casefold() == wanted:
                    return item.channel
            raise ConfigurationError(
                f"No motor is named {reference!r} in hardware.py. "
                f"Configured names: {', '.join(item.name for item in self.motors)}"
            )
        if isinstance(reference, bool) or not isinstance(reference, int):
            raise ConfigurationError("Use a motor name or a channel number from 1 through 8")
        return self.motor(reference).channel

    def servo_slot(self, reference: int | str, board: int | None = None) -> ServoSlot:
        """Accept either a servo name or a board/channel pair."""

        if isinstance(reference, str):
            wanted = reference.strip().casefold()
            for slot in self.servos.channels:
                if slot.name.casefold() == wanted:
                    return slot
            raise ConfigurationError(
                f"No servo is named {reference!r} in hardware.py. "
                f"Configured names: {', '.join(slot.name for slot in self.servos.channels)}"
            )
        if isinstance(reference, bool) or not isinstance(reference, int):
            raise ConfigurationError("Use a servo name or a channel number from 0 through 15")
        index = 0 if board is None else board
        if isinstance(index, bool) or not isinstance(index, int):
            raise ConfigurationError("Servo board must be an integer starting at 0")
        if not 0 <= index < len(self.servos.addresses):
            raise ConfigurationError(f"Servo board {index} is not configured")
        if not 0 <= reference < SERVO_CHANNELS_PER_BOARD:
            raise ConfigurationError("Servo channel must be from 0 through 15")
        for slot in self.servos.channels:
            if slot.board == index and slot.channel == reference:
                return slot
        return ServoSlot(name=f"servo_{index * SERVO_CHANNELS_PER_BOARD + reference}",
                         board=index, channel=reference)

    @property
    def motor_names(self) -> tuple[str, ...]:
        return tuple(item.name for item in self.motors)

    @property
    def servo_names(self) -> tuple[str, ...]:
        return tuple(slot.name for slot in self.servos.channels)


def _as_int(value: object, label: str) -> int:
    if isinstance(value, bool) or not isinstance(value, int):
        raise ConfigurationError(f"{label} must be an integer")
    return value
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

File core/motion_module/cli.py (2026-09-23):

"""Read-only checks plus explicitly confirmed bench tests."""

from __future__ import annotations

import argparse
import json
import platform
import subprocess
import sys
import time
from pathlib import Path

from . import __version__
from .config import load_config
from .controller import MotionModule
from .diagnostics import pi_power_check
from .errors import MotionModuleError
from .gpio import is_raspberry_pi
from .pinout import DRIVER_GROUNDS, PHYSICAL_BY_BCM, motor_rows, servo_rows


def _service_active() -> bool:
    if platform.system() != "Linux":
        return False
    result = subprocess.run(
        ["systemctl", "is-active", "--quiet", "motionmodule.service"],
        check=False,
        capture_output=True,
    )
    return result.returncode == 0


def _scan_i2c(config) -> list[dict]:
    results = []
    if not config.servos.enabled:
        return results
    try:
        from smbus2 import SMBus

        with SMBus(config.servos.i2c_bus) as bus:
            for address in config.servos.addresses:
                try:
                    bus.read_byte_data(address, 0x00)
                    results.append({"address": address, "ok": True, "detail": "responded"})
                except OSError as error:
                    results.append({"address": address, "ok": False, "detail": str(error)})
    except (ImportError, OSError) as error:
        for address in config.servos.addresses:
            results.append({"address": address, "ok": False, "detail": str(error)})
    return results


def doctor(as_json: bool = False) -> int:
    checks: list[dict] = []
    try:
        config = load_config()
        checks.append({"name": "configuration", "status": "pass", "detail": "pin map is valid"})
    except MotionModuleError as error:
        checks.append({"name": "configuration", "status": "fail", "detail": str(error)})
        if as_json:
            print(json.dumps({"checks": checks}, indent=2))
        else:
            print(f"FAIL configuration: {error}")
        return 1

    pi = is_raspberry_pi()
    power = pi_power_check(pi)
    checks.append({"name": power["id"], "status": power["level"], "detail": power["detail"]})
    checks.append(
        {
            "name": "platform",
            "status": "pass" if pi else "info",
            "detail": "Raspberry Pi detected" if pi else "development computer; GPIO will be simulated",
        }
    )
    if pi:
        gpio_ok = Path("/dev/gpiochip0").exists()
        try:
            import lgpio  # noqa: F401
        except ImportError:
            gpio_ok = False
        checks.append(
            {
                "name": "gpio",
                "status": "pass" if gpio_ok else "fail",
                "detail": "lgpio and gpiochip0 are available" if gpio_ok else "lgpio or /dev/gpiochip0 is missing",
            }
        )
        spi_active = any(Path("/dev").glob("spidev*"))
        checks.append(
            {
                "name": "spi-pins",
                "status": "warn" if spi_active else "pass",
                "detail": "SPI is active and conflicts with Driver 3" if spi_active else "SPI device is not active",
            }
        )

    for result in _scan_i2c(config) if pi else []:
        checks.append(
            {
                "name": f"servo-0x{result['address']:02x}",
                "status": "pass" if result["ok"] else "warn",
                "detail": result["detail"],
            }
        )
    checks.append(
        {
            "name": "motor-drivers",
            "status": "info",
            "detail": "four drivers are configured; input-only H-bridges cannot identify themselves electronically",
        }
    )
    checks.append(
        {
            "name": "service",
            "status": "pass" if _service_active() else "info",
            "detail": "motionmodule.service is running" if _service_active() else "service is not running here",
        }
    )
    if as_json:
        print(json.dumps({"version": __version__, "checks": checks}, indent=2))
    else:
        print(f"MotionModule {__version__}")
        for check in checks:
            print(f"{check['status'].upper():4} {check['name']}: {check['detail']}")
    return 1 if any(item["status"] == "fail" for item in checks) else 0


def show_pinout() -> int:
    config = load_config()
    print("Motor driver pinout (IN1/IN2 drive each board's MOTOR_A, IN3/IN4 its MOTOR_B)")
    print('Use the name in code: module.motor("name")')
    print("Name          Chan Driver Out  Forward wire        Reverse wire        Inverted")
    for row in motor_rows(config):
        print(
            f"{row['name']:<13} {row['motor']:>4} {row['driver']:>6} {row['output']:>3}  "
            f"{row['forward_input']} pin {row['in1_physical']:>2}/GPIO{row['in1_bcm']:<2}   "
            f"{row['reverse_input']} pin {row['in2_physical']:>2}/GPIO{row['in2_bcm']:<2}   "
            f"{'yes' if row['inverted'] else 'no'}"
        )
    grounds = "; ".join(
        f"Driver {driver} pin {DRIVER_GROUNDS[driver]}" for driver in sorted(DRIVER_GROUNDS)
    )
    print(f"Grounds: {grounds}")
    oe_gpio = config.servos.output_enable_gpio
    oe = "" if oe_gpio is None else f"; OE pin {PHYSICAL_BY_BCM[oe_gpio]}/GPIO{oe_gpio}"
    print(f"Servo I2C: SDA pin 3/GPIO2; SCL pin 5/GPIO3; logic VCC pin 1/3.3V{oe}; GND pin 9")
    print('Servo outputs (use module.servo("name")):')
    for row in servo_rows(config):
        print(f"  {row['name']:<13} board {row['board']} ({row['address']})  channel {row['channel']}")
    return 0


def _require_bench_confirmation(yes: bool) -> None:
    if _service_active():
        raise MotionModuleError("Stop the running service first: sudo systemctl stop motionmodule")
    if yes:
        return
    print("DANGER: raise the robot, clear the mechanism, and keep a physical power switch in reach.")
    answer = input("Type RAISED to continue: ").strip()
    if answer != "RAISED":
        raise MotionModuleError("Bench test cancelled")


def _reference(value: str) -> int | str:
    """Bench commands accept a hardware.py name or a plain channel number."""

    text = str(value).strip()
    return int(text) if text.isdigit() else text
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

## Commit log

2026-08-31 Fix piped Raspberry Pi installation
2026-08-31 Add multi-mode servo commissioning controls
2026-09-02 Fix Raspberry Pi release validation
    [terminal.py]
2026-09-02 Add browser Driver Station deployment
2026-09-17 Redesign the dashboard and Driver Station as a clean robot controller
    Bring the aloeveraz.github.io design language to both robot pages: Barlow
    Condensed headings over Inter, warm ink on near-black, a steel-blue accent,
    pill controls, rounded panels, and a blueprint grid background. Status lights
    keep their green, yellow, and red meanings.
    - Share one stylesheet and appearance script from core/motion_module/static,
    linked with a content hash and cached by browsers for a week.
    - Self-host the fonts (SIL OFL 1.1) so the robot hotspot needs no internet.
    - Keep every page script, element id, and safety behavior; fix the Driver
    Station heading dial, whose needle never rotated in a r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
    [dashboard.py, test_dashboard.py]
2026-09-17 Redesign the dashboard and Driver Station as a clean robot controller
    Station heading dial, whose needle never rotated in a real brows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
    [dashboard.py, test_dashboard.py]
2026-09-17 Make installs replace MotionModule so branches are interchangeable
    A Pi on main can install testing, and a Pi on testing can install main,
    without files from one branch lingering beside the other.
    Once the new release is active and its service has stayed up for a few
    seconds, the installer removes what older installs left behind: every
    other release, MotionModule scripts, sudo rules, services, and nginx sites
    this version does not ship, leftover upload archives, and any temporary
    terminal access code. Robot projects and their backups, the active
    project, hardware.py pin names, and Wi-Fi settings are never removed.
    An earlier release of the same branch stays for `motionmodule roll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
2026-09-17 Make installs replace MotionModule so branches are interchangeable
    An earlier release of the same branch stays for `motionmodule rollback`;
    a r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
2026-09-17 Explain branch switching in the testing notice
2026-09-17 Add a one-command laptop demo of the dashboard
    Run the real dashboard and Driver Station on any computer, with a
    simulated robot, to show the UI off or work on it without a Pi:
    irm https://raw.githubusercontent.com/AloeVeraZ/MotionModule/testing/demo.ps1 | iex
    curl -fsSL https://raw.githubusercontent.com/AloeVeraZ/MotionModule/testing/demo.sh | bash
    The launchers download the branch (or use the clone they sit in), set up a
    private Python environment, and start motion_module.demo, which serves the
    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
2026-09-17 Add a one-command laptop demo of the dashboard
    example Mecanum robot through MotionModule's motor and servo simulation.
    Simulated cameras, IMU, Pi inputs, and a USB sensor board keep the Driver
    Station moving; network changes, deployme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
2026-09-17 Keep the Windows demo download under the path length limit
    Unpack into short folder names so Windows PowerShell can extract every file, hide Expand-Archive's per-file cleanup noise, and say when unpacking, not only downloading, failed.
2026-09-17 Read robot sensors through the Arduino GIGA, flashed from the Pi
    The GIGA R1 WiFi now works as the robot's sensor extender, with no Arduino
    IDE anywhere in the setup.
    - firmware/giga_sensor_bridge: one sketch for every robot. It reads digital
    pins as 1/0 and analog pins as 0-4095, drives a BNO055 9-axis and an
    LSM6-family 6-axis IMU without Arduino libraries (gyro bias measured at
    rest, yaw integrated about the measured up direction), and streams JSON
    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
2026-09-17 Read robot sensors through the Arduino GIGA, flashed from the Pi
    lines at 50 Hz. The original MM1 pins-only protocol still works both ways.
    - firmware/giga_sensor_bridge.bin is prebuilt (firmware/build.py). The Pi
    flashes it with `motionmodule giga flash` or Debug's Install firmware
    button: a 12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
2026-09-17 Make the GIGA a plain sensor board, with the maths on the Pi
    The GIGA is now only a middle man. It reads the pins and I2C registers the Pi
    asks for, at the rate the Pi asks for, and passes the numbers up the cable. It
    knows nothing about any sensor, so its firmware never changes when the robot's
    sensors do, and everything that decides what a reading means lives on the Pi.
    - Firmware 3.0.0 is generic: MM3 CONFIG says which pins and which I2C reads to
    repeat and how often, MM3 I2C does one read or write, MM3 SCAN lists the bus.
    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
2026-09-17 Make the GIGA a plain sensor board, with the maths on the Pi
    Readings carry the board's own millisecond clock so the Pi can measure its
    own intervals. It is 1,400 lines smaller and has no sensor code left in it.
    - New core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
2026-09-17 Check GitHub for updates and install them from the dashboard
    Debug -> Checks & logs opens with a line per branch. Green means this
    robot already runs the newest version of it; red means one is waiting,
    with the commit the Pi has against the commit on GitHub. A Pi installed
    from testing also sees main, so it can go back to stable; a Pi on main
    sees only main.
    The Pi asks GitHub with git ls-remote, which needs no token and has no
    rate limit, and compares the answer against the commit the installer
    records in INSTALL_COMMIT. A check that fails says so rather than
    guessing, so a robot on its own hotspot never claims to be current.
    Pressing Update now stops the outputs and hands the branch to a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
    [dashboard.py, test_dashboard.py, updates.py]
2026-09-18 Check GitHub for updates and install them from the dashboard
    Debug -> Checks & logs opens with the main line: green when this robot
    already runs its newest version, red with Update now when one is
    waiting, and the commit the Pi has against the commit on GitHub.
    now records in INSTALL_COMMIT. A check that fails says so rather than
    Pressing Update now stops the outputs and hands the branch to a root
    helper the installer adds, restricted to main and testing by a sudoers
    rule. The helper s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
    [dashboard.py, test_dashboard.py, updates.py]
2026-09-18 Draw the Pi 5 beside its pinout and name driver inputs as printed
    The wiring guide now shows a Raspberry Pi 5, drawn to scale, beside the
    header list and turned the same way: ports at the bottom, header down
    the right edge, so pin 1 is top left in both. A short card explains how
    to hold the Pi to match.
    The motor drivers move into their own section under it, with a drawing
    of the dual H-bridge board and what each of its pins does. Output B
    was labelled IN1 and IN2 everywhere, but the board drives MOTOR_B from
    IN3 and IN4, so wiring by the old label put motor B's signals on motor
    A's inputs. The pinout, the pin details, motionmodule pinout,
    hardware.py and the docs now use the names printed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
    [cli.py, hardware.py, hardware_guide.py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]
2026-09-18 Lock the reference wiring so no change can move a pin
    The robot is wired exactly as the Debug header list shows, and that wiring
    works, so it is now fixed on main and testing alike. AGENTS.md, which
    CLAUDE.md pulls in, tells every coding agent that no pin, GPIO, driver,
    output or ground may move, and lists the whole map. The same note sits
    beside the pin maps in pinout.py, both shipped hardware.py files and
    docs/PINOUT.md.
    tests/test_wiring_lock.py checks the built-in and Mecanum pin maps, the job
    of all 40 header pins, the servo board's five wires, and the wiring tables
    in the hardware.py comments, PINOUT.md and the Mecanum README. The
    installer runs the tests, so a release with different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
    [cli.py, diagnostics.py, hardware.py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]
2026-09-18 Move a Pi's old pin maps onto the locked wiring when it installs
    The robot is wired as docs/PINOUT.md shows, and main and testing both ship
    that wiring, but a Pi set up before 6 September kept the pin map it was given
    then. An install never replaced a robot folder or
    ~/.config/motionmodule/hardware.py, so robots/Mecanum went on driving
    front_left on GPIO12 and GPIO6 and the rest of the retired pins, with OE
    unwired, and Debug -> Wiring drew them.
    Every install now runs motion_module.retired_wiring before the new release
    starts. A hardware.py whose eight motors sit exactly on the retired pins is
    replaced with the pin map the release ships for it: the Mecanum sample's in
    robots/Mecanum, the b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
2026-09-20 Give a robot folder nobody edited the sample the release ships
    An install kept every robot folder it found, so the copy of the Mecanum
    sample a Pi was first given stayed on it. The fixes that followed, such as
    a wheel's `inverted` value, only reached the robot if someone downloaded
    the sample and deployed it by hand.
    An install now compares robots/<name> with every copy of that sample
    MotionModule has shipped. A folder whose files are all shipped copies holds
    nobody's work, so it is given the sample this release ships and the folder
    it replaces is kept under ~/MotionModule/backups. One edited or added file
    leaves the whole folder alone, and the install log says which file it was.
    core/moti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
    [deploy.py]
2026-09-21 Fix drivetrain motor bench directions
    [hardware.py, test_controller.py, test_dashboard.py]
2026-09-21 Reboot Pi after dashboard updates
    [test_dashboard.py, updates.py]
2026-09-21 Scope motor polarity to Mecanum sample
2026-09-21 Apply rear motor polarity to legacy Mecanum projects without overwriting code
2026-09-21 Correct Test Mecanum rotation only for observed wheel response
    [mecanum.py, test_dashboard.py, test_mecanum_test_drive.py]
2026-09-21 Share confirmed Mecanum movement with Driver Station and integrate Debug navigation
2026-09-21 Add read-only Pi power diagnostics without changing motor performance
2026-09-23 updt camera logic
2026-09-23 added IMU support
2026-09-23 updt sensor
2026-09-23 added wiring diagram
2026-09-24 timing issue w imu
    [diagnostics.py, imu.py, test_imu_diagnostics.py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]
2026-09-24 fixed servo & IMU
    [dashboard.py, diagnostics.py, hardware_guide.py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]
2026-09-24 updt servo
2026-09-24 added more servo options
2026-09-26 new imu
2026-09-26 imu fin
2026-10-01 Document the Mecanum reference build with photos and supplied enclosure CAD
    [electronics-box.step, motion-module.step]
2026-10-01 Keep current installer tests after merging duplicate branch history
2026-10-01 Clarify open-source controller purpose and provide offline BOM CAD downloads
    [electronics-box.step, motion-module.step]
2026-10-01 Update motion module CAD and document enclosure mounting screws
    [motion-module.step]
2026-10-01 Add four-motor MotionModule Mini with shared runtime and variant-aware dashboard
2026-10-01 Refresh diagnostics every five minutes and use module selection buttons
2026-10-01 Skip GPIO runtime pipes and sockets when backing up robot code
    [project_preservation.py]
2026-10-02 Restore all eight ports when switching Mini projects to full MotionModule
2026-10-19 Keep driver station connected during program changes and add fresh install
2026-10-19 Restore Mecanum gyro autonomous as selectable program
2026-10-19 Rename autonomous sample and unify dashboard controls
2026-10-19 Polish responsive dashboard and driver station layout
2026-10-19 Make built-in IMU available across robot programs
2026-10-19 Latch autonomous overshoot corrections to thirty percent power
2026-10-19 Use PID correction to settle autonomous turns within three degrees
2026-10-19 Fix autonomous gyro feedback direction and tune fast marker turns
2026-11-01 Stop a damaged OpenCV library from taking the dashboard down
    The robot showed 502 because cv2.abi3.so was cut off at 28 MiB, most likely by
    a power cut soon after OpenCV installed itself. Importing it killed the
    dashboard with SIGBUS on every start, which no except clause can catch, so a
    library that is only needed for cameras stopped the whole controller.
    Test OpenCV in a throwaway process before importing it, repair it when a camera
    needs it, and flush the install to the SD card so the power switch cannot
    truncate it.
2026-11-01 Compare shipped samples without relying on directory order
    iterdir() order depends on the filesystem, so this test failed on a Pi's tmpfs
    and could fail on any SD card. The installer runs the tests, so that would
    block the install.
